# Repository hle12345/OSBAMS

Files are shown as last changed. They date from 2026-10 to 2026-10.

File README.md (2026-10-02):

# OSBAMS — Rev.2

> ## Status
> **Release candidate, not bench-validated.** The controller PCB (`Hardware/Rev2_Controller/OSBAMS_Rev2_RELEASE_CANDIDATE_1/`, RC1.2e) is a
> *review* package: ERC/DRC/netlist/schematic-parity checks are clean, but **no physical validation has been run**, the board is
> **not released for fabrication**, and nothing here is BENCH_TESTED or HARDWARE_VALIDATED. Gerbers are intentionally not shipped:
> export them yourself from the KiCad 10 project after re-running ERC/DRC. First-article tests and open items are listed in
> `Hardware/Rev2_Controller/CONTROLLER_PROTECTION_AND_CONNECTOR_AUDIT.md`. Do not connect a real battery pack to hardware built from
> these files without completing `docs/rev2/FIRST_BATTERY_TEST_PROCEDURE.md`.

> **AI assistance.** Developed with AI-assisted engineering tools (including Claude) for code generation, documentation, and design
> review. Final design decisions, hardware validation, and release responsibility remain with the project author/team.

## Licences
* **Software and firmware** (`desktop/`, `Firmware/`, `tools/`, `tests/`, build/calculation scripts): **MIT** — see `LICENSE`.
* **Hardware and hardware documentation** (`Hardware/`, `manufacturing/`, `docs/`, `Documentation/`, KiCad sources): **CERN-OHL-S-2.0** — see `LICENSE-HARDWARE.md`.
* Manufacturer datasheets and CAD models are **not** included; see `docs/rev2/pcb/evidence/SOURCES.md` for where to get them.

**OSBAMS Rev.2 is a standalone lithium-ion battery characterization platform optimized
around the SFSU Agilent 6060B electronic load. It uses an STM32L476RG safety controller,
Raspberry Pi 5 interface, INA228-based measurement, independent voltage verification, and
Keysight reference instrumentation to validate capacity, energy, DCIR, thermal behavior, and
battery health metrics of compatible lithium-ion battery packs within the verified hardware envelope.**

Supported: lithium-ion packs, approximately 30–42 V (10S-class; Ninebot/Segway, Shenzhen Elite), XT60 (connector type does not determine test capability — the validated power path does).
Status: **2.0.0-dev1 — host- and simulator-tested; no physical validation has been run**
(nothing is BENCH_TESTED or HARDWARE_VALIDATED).

## The one rule
`allowed current = min(battery profile, OSBAMS hardware limit, 6060B current limit, 300 W / battery voltage)`
at the conservative (never-sagging) pack voltage. 42 V → **7.14 A**; 36 V → **8.33 A**. The 60 A rating never
overrides 300 W. Operating ceiling: ≤ 44 V and ≤ 10 A until the power path is physically validated.

## The Rev.2 stack (`docs/rev2/SFSU_EQUIPMENT_MATRIX.md`)
Agilent/Keysight **6060B** (primary and only external load) · Keysight **EDU34450A** (reference measurement) ·
**Raspberry Pi 5 + 10.1" touchscreen** (UI, database, passport, reports) · **STM32L476RG** (safety controller) ·
**power path** (battery → XT60 → fuse → disconnect → relay → shunt → 6060B) · Keysight **EDUX1052G** (validation-only observation).

## Test orchestrator and dashboard
`services/test_orchestrator.py`: Capacity (`PROFILE → OCV screen → hardware safety check → capability calculation → READY → CC discharge → cutoff → load OFF verified → recovery → results`) and a separate DCIR current-step test. The dashboard shows the live permitted-current breakdown and drives a *manual* 6060B (operator sets/enables the load; OSBAMS verifies from measurements). Hard invariant: commanded current × conservative pack voltage ≤ 300 W; sag never raises current.

## Open at multiple levels
**Current status of the calibration / validation / AI work (under development)**
- The Rev.2 PCB remains frozen at RC1.2e (release candidate, not bench-validated until first article); the validation/AI work makes no PCB or schematic geometry change.
- Protocol v2 firmware is still under development: only a host-side reference parser, golden vectors and design exist; the STM32 firmware still speaks protocol v1.
- Calibration, measurement-quality and agreement thresholds (and the rule-baseline thresholds) are provisional until real bench/reference-instrument measurements exist.
- The AI/data work is experimental/research-stage; no ML-based battery-health result is production-valid yet, and capacity retention vs rated is not a validated cell-level SOH.

OSBAMS is a platform for assessing unknown and second-life batteries, not just a low-cost cycler: **open hardware** (Rev.2 controller PCB review package), **open firmware and software**, **open battery profiles and test protocols**, **open standardized data** (`docs/rev2/DATASET_SCHEMA.md`, Battery Passport) and **open health models** (`ai/`). Chain: Rev.2 hardware → calibration/validation layer → real battery dataset → explainable AI health assessment. The calibration/validation and AI work is **under development**: thresholds are provisional until reference-instrument validation, Rev.2 remains unbench-validated until first article, AI health estimation is experimental/research-stage, and capacity retention is not a validated cell-level SOH. See `docs/rev2/WORKSTREAMS.md`, `docs/rev2/VALIDATION_AND_CALIBRATION_PLAN.md`, `ai/README.md`.

## Next milestone: first real battery test
`docs/rev2/FIRST_BATTERY_TEST_PROCEDURE.md`, with `CALIBRATION_RECORD_TEMPLATE.md` and `HARDWARE_ACCEPTANCE_RECORD.md`. Software is ahead of hardware; no more features until measurements exist.

## Bench work
`docs/rev2/BENCH_CHECKLIST.md` — the exact physical tests, in order (workflow: `LV_HARDWARE_VALIDATION_PLAN.md`; verification: `INSTRUMENT_CALIBRATION_PLAN.md`). `docs/rev2/6060B_DRIVER_EVIDENCE.md` — remote-control command evidence (nothing VERIFIED yet).

## Controller PCB manufacturing package
`manufacturing/PCBWay_OSBAMS_Rev2_PCBA/` — candidate Gerber/BOM/CPL/PDFs for the KiCad controller PCB, with a design review and checklist. **Not production-ready** (see its README and checklist).

## Layout
- `desktop/` — Python application (`equipment/`, `services/`, `db/`, `gui/`)
- `Firmware/` — STM32 firmware + host C tests
- `docs/rev2/` — architecture, power-path matrix, current-sensing redesign, GPIB checklist, validation plan, baseline
- `legacy/rev1/` — archived Rev.1 code (nothing may import it)
- `tests/`, `tools/` — Python tests; simulator and demo-data tools

## Run the tests
```
pip install pytest numpy scikit-learn
python3 -m pytest tests          # also: pyserial PySide6 pyqtgraph; QT_QPA_PLATFORM=offscreen
make -C Firmware/Tests run
```
Learning Mode demo: `cd desktop && python3 -m services.learning_mode`.
Simulator: `python3 tools/simulate_serial.py --list`.

## 6060B remote control
`6060B_REMOTE_CONTROL = BLOCKED_BY_INTERFACE_CONFIRMATION` until the lab's GPIB
path is confirmed (`docs/rev2/GPIB_INTERFACE_CONFIRMATION.md`). Use `Manual6060B`
or `Simulator6060B` meanwhile.

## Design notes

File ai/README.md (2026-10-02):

# OSBAMS `ai/` — experimental health-assessment area

**Experimental / research stage.** Nothing here is a validated battery state-of-health or a safety certification. Thresholds are
provisional until reference-instrument validation and real labelled data exist. Capacity retention (measured usable ÷ rated) is not
a validated cell-level SOH.

Layout: `features/` (feature definitions, quick-test features) · `assessment/` (non-ML rule baseline: REUSE_CANDIDATE / MONITOR /
RETEST_REQUIRED / RECYCLE_CANDIDATE with reason codes; missing inputs or non-PASS quality can only give RETEST_REQUIRED) · `models/`
(small explainable zoo: linear/logistic, random forest, gradient boosting, Gaussian process — no deep networks) · `training/` (refuses to
train without enough validated, labelled batteries; synthetic data only with explicit opt-in) · `evaluation/` (split by battery identity,
metrics) · `datasets/` (clearly labelled SYNTHETIC generator and sample) · `model_registry/` (append-only record of dataset version, feature
version, model type, battery count, chemistry coverage, protocol, metrics, limitations).

The AI work uses the exported dataset (`docs/rev2/DATASET_SCHEMA.md`) or synthetic/test CSVs; it does not depend on protocol v2.
Quick Health Test: `docs/rev2/QUICK_HEALTH_TEST_RESEARCH.md`.

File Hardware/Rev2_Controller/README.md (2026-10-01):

# OSBAMS Rev.2 Controller (new integrated design)

Status: **RELEASE CANDIDATE 1.2 — design package for REVIEW. NOT final, NOT released for fabrication.**
- `OSBAMS_Rev2_RELEASE_CANDIDATE_1/` — KiCad 10 project (schematic, 4-layer PCB, TC74 probe board), BOM/CPL (no Gerbers: export them from the final PCB in KiCad 10), PDFs, ERC/DRC reports, evidence register, supply-chain/DFM/assembly/fab notes, `PCBWAY_RELEASE_CANDIDATE_REPORT.md` (READY FOR REVIEW / BLOCKERS BEFORE PCBWAY ORDER).
- `REV2_CONTROLLER_ARCHITECTURE.md` — architecture (rev D, matches RC1)
- `REV2_CALCULATIONS.md` — generated: `python3 Hardware/Rev2_Controller/calc/rev2_calcs.py` (inputs: `calc/datasheet_inputs.json`, evidence states VERIFIED_LOCAL / USER_RELAYED_MANUFACTURER / UNVERIFIED)
- `REV2_BLOCK_DIAGRAM.png/.svg` (`calc/make_block_diagram.py`), `DATASHEET_VERIFICATION.md` (evidence register)
- `design/` + `build_rc1.py` + `finalize_rc1.py` — generator pipeline (single source of truth `design/rev2_design.py`); `BUILD_ENVIRONMENT.md` explains the KiCad 10 container (`tools/kc10`).
- `reference/` — superseded drafts. Rev.1 KiCad: `legacy/reference/rev1_kicad/` (reference only).
Order: RC1 review → clear every blocker in the RC1 report (manufacturer PDFs, EB21A drawing, local ERC/DRC and Gerber regeneration, stock/lifecycle) → gates in `docs/rev2/pcb/RELEASE_GATES.json` → PCBWay.

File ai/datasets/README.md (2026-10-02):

# Datasets

`synthetic_sample.csv` and `synthetic.py` are **SYNTHETIC**: invented numbers from a made-up relation, for exercising the pipeline. They are
not measurements, not battery physics, and must never be cited as evidence. Real data come from `desktop/services/dataset_export.py`
(`docs/rev2/DATASET_SCHEMA.md`); contribute only anonymized exports.

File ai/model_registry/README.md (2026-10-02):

# Model registry
`registry.py` appends one JSON line per trained model (`registry.jsonl`, created on first use): model type, dataset and feature versions,
training battery count, chemistry coverage, test protocol, validation metrics, explanation, limitations, and a `synthetic` flag. A registry
entry is a record of what was done, not a claim that the model is validated.

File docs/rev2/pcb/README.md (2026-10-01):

# Controller PCB — status and documents
- `MANUFACTURING_STATE.md` — no package exists; gates in `RELEASE_GATES.json`
- `REV2_SCHEMATIC_PCB_PLAN.md` — proposed revision (board not modified)
- `BENCH_V1_V10_ONE_PAGE.pdf` / `.md` — hand-fill bench sheet (`python3 -m tools.mfg.bench_sheet`)
- `APPROVED_DECISIONS.md` — user decisions 2026-10-01
- `RELAY_VERIFICATION.md`, `PI_POWER_ARCHITECTURE.md`
- Audit inputs (unchanged): `PCBWAY_READINESS_GAPS.md`, `PCBWAY_REV2_CHANGE_REQUEST.md`, `REV1_HARDWARE_TRUTH_INVENTORY.md`
- `REV1_BOARD_*_SNAPSHOT.md` — historical

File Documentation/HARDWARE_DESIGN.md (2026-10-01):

# OSBAMS Hardware Design

> **Naming:** Rev.2 calls the sides "A. battery / discharge power path" and "B. low-voltage control / instrumentation path" (see `docs/rev2/HARDWARE_FREEZE_CANDIDATE.md`).
>
> **Rev.2 note:** the Rev.1 design below is retained for history. Rev.2 power-path limits and the redesign needed to use more of the 6060B envelope are in `docs/rev2/LV_POWER_PATH_CAPABILITY.md`; targets above 60 V are out of scope.

**Build:** 0.9.0-dev1 — Engineering Prototype
**Status:** The architecture is defined and captured in a block schematic. The
design is **not frozen**: the contactor, E-stop, sensor front end, and power
supply are still being selected, and no board has been built or bench-verified.
This document describes the intended design and marks what remains open.

Supporting files:
- `hardware/schematic/OSBAMS_schematic.svg` / `.png` — block schematic
- `hardware/bom/OSBAMS_BOM.csv` — bill of materials (27 line items)
- `hardware/wiring/CONNECTION_TABLE.md` — pin/net connection table
- `hardware/Calculations/` — fuse, shunt, divider, thermal calculations (pending)

---

## 1. Design intent

OSBAMS is a bench fixture for discharging and measuring second-life 10S NMC
packs (36 V nominal, 42 V maximum, up to ~10 A). It is an engineering
instrument, not an EV drivetrain, so switching and protection are sized to the
actual energy of the pack under test — not to hundreds of amps.

Two guiding principles:

1. **Physical safety does not depend on firmware.** An E-stop must remove
   contactor-coil power by hardware, even if the firmware hangs, USB is removed,
   or the desktop freezes.
2. **The controller survives a pack disconnect.** Control power is separate from
   the pack, so the STM32 can save state, log the fault, and send the last
   telemetry when the pack is removed.

---

## 2. High-energy power path

```
Battery +  →  keyed connector (J1)  →  58 V DC fuse (F1)
           →  Blue Sea manual disconnect (SW1)
           →  DC contactor (K1)
           →  precision shunt (RS1) / INA228
           →  electronic load
           →  Battery −  (single-point star ground)
```

Notes and open items:
- **Connector (J1):** keyed/polarised (XT60 or Anderson) so the pack cannot be
  connected backwards casually.
- **Fuse (F1):** DC-rated with a **documented DC interrupt rating** at this
  voltage — not a generic automotive fuse. Value from `hardware/Calculations/`
  (pending).
- **Manual disconnect (SW1):** Blue Sea 6006, a physical service disconnect that
  breaks the pack rail.
- **Contactor (K1):** a **DC-rated** contactor with a published DC breaking
  rating for 42–60 V under load. The specific part is **not yet frozen** — this
  is the single most important remaining hardware selection, and it must not be
  a generic relay whose datasheet lacks a DC interrupt rating.
- **Shunt (RS1):** external shunt sized so full-scale current stays within the
  INA228's ±163.84 mV shunt range. Kelvin connection. Value pending calibration.

---

## 3. Control path (separate 12 V)

```
120 VAC  →  12 V supply (PS1)
         ├─────────────────────────────┐
         │                             │
  contactor-coil branch          5 V branch
   F2 control fuse                12→5 V converter
   ARM switch (SW2)               →  STM32
   E-stop NC (ES1)
   MOSFET low-side driver (Q1)  →  contactor coil (K1)
```

The E-stop is wired in series with the contactor coil supply as a
**normally-closed** contact, so opening it de-energises the coil directly,
independent of the STM32. The MOSFET (Q1) is only the low-side switch the STM32
uses to command the coil **within** that safety chain — it cannot override an
open E-stop. A flyback/suppression diode across the coil is required (see BOM).

Open items: the E-stop part, the 12 V supply, and the MOSFET are selected in the
BOM as starting points but not frozen.

---

## 4. Measurement and sensing

| Quantity | Device | Notes |
|---|---|---|
| Bus voltage, current, power, energy, charge | INA228 (U2) | primary metrology; 85 V bus covers 42 V pack; external shunt |
| Redundant voltage | STM32 ADC via protected divider | diverse cross-check, gross-error only, **not** certified-independent |
| Pack temperature | TC74 (U3) | I²C, 1 °C resolution |

The INA228 and TC74 share the I²C bus (PB8/PB9) with pull-ups. The ADC divider
scales the 42 V pack into the 3.3 V ADC range; its exact ratio, resistor
tolerances and voltage ratings, RC filter, input protection, and ADC sample time
are part of the analog design still to be finalised in `hardware/Calculations/`.

---

## 5. STM32 connections

| Signal | Pin | Direction | To |
|---|---|---|---|
| I²C SCL / SDA | PB8 / PB9 | bidir | INA228, TC74 |
| Load enable | PC8 | out | Q1 gate (contactor coil driver) |
| Contactor aux feedback | PC9 | in | K1 auxiliary contact |
| E-stop sense | PA0 | in | E-stop / disconnect status |
| UART TX / RX | PA2 / PA3 | bidir | USB virtual COM (host) |
| Heartbeat LED | PA5 | out | status LED |
| Redundant voltage | ADC channel | in | protected divider |

Full net-by-net detail is in `hardware/wiring/CONNECTION_TABLE.md`.

---

## 6. Protection (engineering review pending)

The following must be reviewed and specified before the design is frozen. They
are listed here so the gap is explicit, per the design review:

- DC fuse interrupt rating at the working voltage
- TVS / transient suppression on the pack input
- Reverse-polarity handling (keyed connector in V1; firmware polarity check)
- Contactor-coil flyback / bidirectional suppression
- Shunt Kelvin connections
- USB ESD protection
- Grounding and ground-loop control (single-point star)
- Connector touch safety, covered terminals, cable strain relief
- Enclosure with separation of high-energy wiring from logic

---

## 7. Bill of materials

See `hardware/bom/OSBAMS_BOM.csv`. Each line item carries manufacturer, part
number, rating, quantity, supplier, and Installed/Verified status. The
biggest-ticket item is the contactor. Every "Verified" field is currently No,
because nothing has been built. Before the design is frozen, the BOM must have a
DC-rated contactor and fuse with documented interrupt ratings, a finalised shunt
value, and an approved substitute for each critical part.

---

## 8. What "frozen" will require

The hardware moves from Engineering Prototype to a frozen revision only when:

- the schematic is complete (not a block diagram) and reviewed,
- the BOM has exact, in-stock parts with documented DC ratings,
- the protection review in §6 is closed,
- the board (PCB or well-organised perfboard) is built and matches the schematic,
- and the acceptance tests in `VALIDATION_REPORT.md` that touch hardware pass
  with recorded data.

Until then this remains a documented design, not verified hardware.

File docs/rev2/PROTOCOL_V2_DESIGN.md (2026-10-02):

# Serial protocol v2 — design (firmware NOT changed)

**Status: design plus a host reference implementation (`desktop/services/protocol_v2.py`). The STM32 firmware still speaks protocol v1.
Nothing here has run on hardware.** v1 (`services/protocol.py`, CRC-16/CCITT-FALSE) stays authoritative for the existing firmware and is
still accepted by `parse_any`.

## Why
The three-way capacity cross-check (`VALIDATION_AND_CALIBRATION_PLAN.md` §4) needs three things v1 does not carry: the independent STM32
ADC voltage, the INA228's own charge/energy accumulators, and the STM32's own timestamp-based integration, plus counters and a
sensor-status word so the Pi can tell "unavailable" from "zero" and "lost frame" from "lost acquisition".

## Frame
`OSBAMS,2,<seq>,<tick_ms>,<V_mV>,<I_mA>,<P_mW>,<T_C10>,<flags>,<state>,<V_adc_mV>,<Q_ina_uAh>,<Q_mcu_uAh>,<E_ina_uWh>,<E_mcu_uWh>,<acq_count>,<sensor_status>,<CRC16>`
(18 fields). Fields 0–9 mean exactly what they mean in v1. Fields 10–14 are integers or the literal `NA`; `NA` is never replaced by 0.
Field table, accumulator rules and `sensor_status` bits: module docstring of `protocol_v2.py` (SS_INA_FAULT, SS_ADC_FAULT, SS_TEMP_FAULT,
SS_ACCUM_INVALID, SS_TIME_JUMP).

## Rules
1. v1 backward compatibility: a v2 reader accepts v1 frames (new fields unavailable); a v1 reader never sees a v2 frame unless the
   firmware is upgraded.
2. All four accumulators reset together at an explicit test-start command. A decrease between frames, or `SS_ACCUM_INVALID`, makes the
   Pi flag `CAPACITY_VALIDATION_WARNING`; it never silently re-baselines.
3. INA228 accumulators are valid only when ADCRANGE/SHUNT_CAL match the active calibration profile (firmware sets `SS_ACCUM_INVALID` otherwise).
4. Like-for-like: the device integrates its own uncalibrated readings, so the agreement check uses the RAW Pi samples; the calibrated Pi
   result is reported separately and is the one used for capacity retention.
5. Nothing in the protocol can change relay, E-stop or load-control behaviour.

## Test-first firmware plan
Golden frames: `docs/rev2/protocol_v2_test_vectors.json` (valid, NA fields, v1 still accepted, bad CRC, wrong field count). Host tests:
`tests/test_protocol_v2_and_data.py`. Firmware order of work: (1) add C tests in `Firmware/Tests` that encode/parse these vectors; (2)
implement the encoder; (3) expose the INA228 CHARGE/ENERGY registers; (4) add STM32 timestamp integration; (5) bench-compare on the
first-article rig. The Pi side and the AI/data work do not wait for any of this.

## Pi-side comparison at test completion
`services/capacity_validation.py`: `AccumulatorTracker` consumes samples, `validate()` returns Ah and Wh per method, % disagreement,
sample and missing-sample counts, calibration id, firmware version, PCB revision, and status `OK` / `CAPACITY_VALIDATION_WARNING` /
`INSUFFICIENT` (fewer than two totals available — never reported as agreement). The warning threshold is **PROVISIONAL** (default 1 %,
configurable) until bench data set it. Persisted by `run_persistence.save_capacity_validation`.

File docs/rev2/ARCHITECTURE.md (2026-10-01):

# OSBAMS Rev.2 architecture

## Identity
> OSBAMS Rev.2 is a standalone lithium-ion battery characterization platform
> optimized around the SFSU Agilent 6060B electronic load. It uses an
> STM32L476RG safety controller, Raspberry Pi 5 interface, INA228-based
> measurement, independent voltage verification, and Keysight reference
> instrumentation to validate capacity, energy, DCIR, thermal behavior, and
> battery health metrics of compatible lithium-ion battery packs within the
> verified hardware envelope.

Supported batteries: lithium-ion (NMC/NCA/LFP), approximately 30–42 V, 10S-class
(Ninebot/Segway, Shenzhen Elite). Connector: XT60 = supported; connector type does not determine test capability — the validated power path does.
Removed scope is recorded only in `docs/research/OUT_OF_SCOPE_FOR_REV2.md`.

## The Rev.2 equipment stack
1. **Agilent/Keysight 6060B** — the only external load; primary test load (CC/CV/CR; capacity, energy, DCIR steps).
2. **Keysight EDU34450A** — reference measurement for calibration/verification; not in the automated loop.
3. **Raspberry Pi 5 + 10.1" touchscreen** — UI: test control, live dashboard, SQLite database, battery passport, reports, analysis.
4. **STM32L476RG** — real-time safety controller: acquisition, relay control, fault handling, watchdog, E-stop monitoring.
5. **Power path** — battery → XT60 → fuse → disconnect → relay → current shunt → 6060B.
6. **Keysight EDUX1052G** — validation only: relay switching, shutdown timing, transients, load-enable behavior.

*The Pi requests actions. The STM32 authorizes them.* (Design principle; today the orchestrator supervises a manual 6060B and verifies load-off from measurements — it does not command the STM32.)

## Envelope
`allowed current = min(battery profile, OSBAMS hardware limit, 6060B current limit, 300 W / battery voltage)`
using the **conservative pack voltage** (max of OCV and highest seen, never lowered by sag) and including the
fuse, disconnect, relay, shunt, wiring and connector limits inside "OSBAMS hardware". 42 V → 7.14 A; 36 V → 8.33 A.
The 60 A rating never overrides 300 W. Operating ceiling: **≤ 44 V, ≤ 10 A (provisional)** until the power path is
physically validated. The firmware hard trip (18.5 A / 60 °C) is a separate protection boundary, not an input to the minimum.

## Test pipeline
```
battery profile → OCV screen → hardware safety check → 6060B capability calculation
→ controlled load test → live logging → Ah/Wh integration → DCIR step
→ automatic cutoff → recovery → SOH / report / passport
```
`services/test_orchestrator.py`: `CapacityTest` (OCV, constant-current discharge, Ah, Wh, voltage sag, thermal
monitoring, automatic profile cutoff, verified load-off, recovery) and a separate `DcirTest` (current steps). The
hardware safety check logs each check (registry status, temperature present and in limits, voltage envelope, positive
permitted current, ceiling below firmware trip, load idle) and blocks before any load command. FAULT paths always turn the
load off and verify it from measured current. Results: `services/run_persistence.py`; history, grading, report and
passport use the existing registry/DB/PDF modules. The dashboard shows pack voltage, profile limit, OSBAMS limit, 6060B
rating, power-derived limit, FINAL PERMITTED and the limiting factor.

## Code map (`desktop/equipment/`)
`capability.py` (envelope + invariant) · `inventory.py` (stack) · `drivers/` (`Keysight6060B` — blocked; `Manual6060B` — working mode; `Simulator6060B`) ·
`reference/` (EDU34450A calibration records) · `validation.py` (ordered bench workflow → `BENCH_CHECKLIST.md`).
Driver evidence: `6060B_DRIVER_EVIDENCE.md`.

## Smart BMS
Supported, documented low-voltage lithium-ion packs, normal read-only communication only. Nothing is implemented or verified,
so every pack reports `SMART_PACK_UNSUPPORTED`. No BMS bypass.

## Known gaps (honest status)
- 6060B remote control: no confirmed GPIB path and no command VERIFIED (the official manuals were not readable from the build environment).
- Orchestrator/dashboard are host- and simulator-tested only; the Pi 5 deployment is untested; **no physical validation has been run** — nothing is BENCH_TESTED or HARDWARE_VALIDATED.
- Power-path parts not yet read off the hardware; the 15 A fuse sits below the 18.5 A firmware trip (decision open).
- TC74 not brought up: thermal protection unvalidated; the safety check refuses to start without a temperature reading.
- No variable source is part of the stack, so voltage/current are verified at the pack's own operating points (`INSTRUMENT_CALIBRATION_PLAN.md`).

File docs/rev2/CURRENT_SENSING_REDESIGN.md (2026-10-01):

# Current sensing — no redesign planned

**Decision:** the Rev.1 current path (RSA-20-50, 2.5 mΩ, ~20 A class, INA228) is
**kept unchanged**, and the OSBAMS operating ceiling stays at **10 A,
provisionally** (`config.SAFETY_MAX_CURRENT_A`).

Why: every supported pack is 36–42 V (≤ 44 V ceiling). The 6060B's 300 W limit
allows 300 / 42 = **7.14 A** (8.33 A at 36 V), and the profiles are lower still.
The existing path already exceeds any current these packs can be loaded with.

Layered limits (distinct concepts, deliberately not equal):

| Layer | Value | Meaning |
|---|---|---|
| Firmware hard safety trip | 18.5 A | absolute protection boundary |
| OSBAMS operating ceiling | 10 A | operating/test boundary (provisional) |
| 6060B @ 42 V | 7.14 A | `min(60 A, 300 W / V)` |
| Battery profile | e.g. 1–5 A | per pack |
| **Commanded maximum** | **min of the operating layers** | e.g. 5 A for a profile limit of 5 A |

The only thing to measure is whether the existing shunt/INA228 is accurate enough at
the 1–3 A test currents — that is bench step E1, not a redesign.

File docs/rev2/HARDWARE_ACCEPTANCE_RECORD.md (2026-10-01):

# Hardware acceptance record — OSBAMS Rev.2 power path and controls

Complete before the first battery connection (`FIRST_BATTERY_TEST_PROCEDURE.md` §1). Read every part number **off the
installed part**; the "expected" column is what the repository says, not proof. Anything not read stays UNKNOWN.
This record does not make the hardware BENCH_TESTED or HARDWARE_VALIDATED; it records what is installed.

## 1. Identification
| Field | Value |
|---|---|
| Unit / enclosure | |
| Date / operator | |
| Software commit / firmware version | |
| Photos stored at | |

## 2. Power path — as installed
| Ref | Part | Expected (source) | **As-installed part number** | Rating read from datasheet | Datasheet ≥ requirement? | Verified (Y/N) |
|---|---|---|---|---|---|---|
| J1 | Battery connector | Amass XT60 (BOM, purchase list: genuine XT60; datasheet figures: ~500 V DC, 60 A on 8 AWG, lower on thinner wire) | | | needs ≥ 10 A at the 12 AWG wire in use | |
| F1 | Main DC fuse | **15 A**, ≥ 58 V DC, Littelfuse/Eaton DC fuse (purchase list: "HOLD - verify part") | | | DC interrupt rating documented? | |
| FH1 | Fuse holder | Littelfuse 0FHM0001ZXJ-RED holder (per purchase record; verify DC V/A rating — V5) with fuse Littelfuse 0997015.WXN 15 A / 58 V | | | accepts the chosen fuse style? | |
| SW1 | Manual disconnect | Blue Sea 6006 (48 V DC max, 300 A continuous, 25 A switching — distributor listings) | | | ≥ 44 V system ceiling | |
| K1 | Relay / contactor | firmware records **Durakool DG57CM-5021-76-1012-R** (no aux contact). BOM/purchase spreadsheets still say Albright SW60 — stale | | | DC rating at ≥ 44 V / 10 A from the datasheet for THIS suffix; coil voltage 12 V? | |
| RS1 | Current shunt | firmware: **RSA-20-50** (2.5 mΩ, 20 A / 50 mV); purchase list: "15 A or 20 A / 50 mV candidate" | | | rating, tolerance, power | |
| W1 | Power wiring | 12 AWG, ≥ 60 V insulation | | | ampacity for the cable actually fitted | |
| — | Ring terminals / lugs | matched to studs | | | | |

Layered limits to confirm against the above: battery profile · 6060B 300 W/V · **OSBAMS operating limit 10 A** ·
**fuse 15 A (abnormal fault current only)** · firmware trip 18.5 A · shunt 20 A. Enter any rating that is *below* 10 A here: ____

## 3. Control and measurement hardware — as installed
| Ref | Part | Expected | As-installed | Notes |
|---|---|---|---|---|
| U1 | STM32L476RG Nucleo-64 | NUCLEO-L476RG | | |
| U2 | INA228 | Adafruit 5832 breakout | | shunt cal matches RS1? |
| U3 | TC74 | TC74A0-5.0VAT (address 0x48) | | **thermal protection unvalidated until working**; attachment point on the pack: |
| Q1 / D1 | coil driver / flyback | IRLZ44NPBF / 1N5408G (per purchase record; confirm installed — V8) | | |
| ES1 | E-stop (NC) | Eaton M22-PV-K02 (per purchase record; verify NC contact count — V6) | | wired in series with the coil supply |
| SW2 | ARM switch | C&K T102SHZQE SPDT (per purchase record; verify — V6) | | |
| PS1 | 12 V supply | Mean Well XDR-75-12 (12 V / 6.24 A / 74.88 W) | | purchase list only says "≥ 2 A, TBD" |
| DCDC1 | 12→5 V | undefined — decision pending, see `pcb/PI_POWER_ARCHITECTURE.md` (external 5 V recommended) | | **a Pi 5 needs a much larger 5 V budget — specify before powering the Pi from it** |
| VO610A feedback | K1 voltage feedback on PC9 | firmware: PC9 = VO610A, active low | | confirm wiring matches |
| ADC divider | independent voltage channel | **unfinished** (purchase list: "DO NOT ORDER YET") | | needed for bench step C2 |
| TVS | pack-input protection | **unfinished** (purchase list: hold) | | |

## 4. Visual and wiring checks (power off, pack not connected)
- [ ] Matches `HARDWARE_FREEZE_CANDIDATE.md` power path; shunt in series; sense leads on the Kelvin terminals
- [ ] High-energy wiring separated from logic; studs covered; strain relief; labels (polarity, fuse rating)
- [ ] Enclosure grounding present

## 5. Continuity / polarity (EDU34450A, power off)
| Check | Reading | OK? |
|---|---|---|
| + to − (must be open) | | |
| Relay contacts, coil de-energised (must be open) | | |
| Fuse continuity | | |
| Shunt resistance | ____ mΩ (expect ≈ 2.5 mΩ if RSA-20-50) | |
| Polarity marks match meter test of the connector | | |

## 6. Safety-function checks (no battery) — bench steps B2, B3
| Function | Expected | Result | Evidence file |
|---|---|---|---|
| Relay default state | open after reset/brown-out/unprogrammed MCU | | |
| E-stop de-energises the coil with the firmware dead (MCU held in reset) | coil off | | |
| ARM off → no relay command | | | |
| Sensor unplugged → FAULT, load-enable OFF | | | |
| Host disconnect → FAULT/safe state | | | |
| Relay close / open times (EDUX1052G, ≥ 10 repetitions) | recorded | | |

## 7. 6060B interface (remote control stays blocked until confirmed)
| Question | Answer |
|---|---|
| Rear-panel interface present (GPIB connector, any other)? | |
| GPIB address setting | |
| USB↔GPIB adapter / LAN↔GPIB gateway / GPIB-equipped PC available at SFSU? | |
| Result | `6060B_REMOTE_CONTROL = BLOCKED_BY_INTERFACE_CONFIRMATION` until a concrete interface is identified **and** commands are VERIFIED (`6060B_DRIVER_EVIDENCE.md`). The first battery test uses the manual front panel. |

## 8. Decision
☐ **ACCEPTED for the first relay-open / low-current test** — all rows in §2 and §3 for the power path and E-stop read and recorded, no rating below 10 A, §6 checks pass.
☐ **NOT ACCEPTED** — reasons: ____

Operator / date: ____________   Reviewer / date: ____________

Statuses BENCH_TESTED and HARDWARE_VALIDATED are not set here. They may be claimed only for what the executed
bench steps (`BENCH_CHECKLIST.md`) actually measured, with data stored.

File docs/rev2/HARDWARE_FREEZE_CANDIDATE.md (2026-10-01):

# Rev.2 hardware — freeze candidate

Status: **candidate, not frozen.** Exact installed part numbers are still to be read off the
hardware (§6; record them in `HARDWARE_ACCEPTANCE_RECORD.md`). Nothing here is bench-validated.

Naming: the two sides are **A. Battery / discharge power path** and
**B. Low-voltage control / instrumentation path** — not "HV/LV". The battery
side is only ~30–44 V for the packs on hand.

## 1. Envelope (layered; three different things)
| Layer | Value | Notes |
|---|---|---|
| 6060B instrument rating | 3–60 V, 60 A, 300 W | `I_max = min(60 A, 300 W / V)`; not an OSBAMS claim |
| **OSBAMS system ceiling (provisional)** | **44 V**, **10 A** | `config.OSBAMS_VALIDATED_MAX_VOLTAGE_V`, `SAFETY_MAX_CURRENT_A`; the finished system is **not** a "60 V system" |
| Firmware hard trip | 18.5 A, 60 °C | protection boundary, not an operating limit |
| Pack at 42 / 36 / 30 V (6060B) | 7.14 / 8.33 / 10 A | power-limited first |

## 2. A. Battery / discharge power path
```
USED Li-ion PACK (10S-class, ~30-42 V) → XT60 connector (adapter only if needed)
  → FUSE (15 A target) → BLUE SEA 6006 manual disconnect
  → DURAKOOL DG57CM relay (SPST-NO, 12 V coil; firmware records DG57CM-5021-76-1012-R)
  → CURRENT SHUNT (existing 20 A class, Kelvin sense, IN SERIES with the current)
  → AGILENT 6060B (3-60 V / 60 A / 300 W) → battery −
```
| Part | Rating used | Verification level |
|---|---|---|
| Blue Sea 6006 | 48 V DC max, 300 A continuous, **25 A switching** | manufacturer-spec values as shown in distributor listings; not read from a Blue Sea datasheet here |
| Durakool DG57CM | DC switching ~80 A@12 V, 60 A@36 V, 50 A@48 V, 145 V DC max, 6–50 V coils — **depends on the exact variant** | from the Durakool product listing; exact suffix of the physical relay NOT yet read |
| Fuse | 15 A target | part/holder not confirmed; needs a DC voltage rating ≥ 44 V (≥ 48 V preferred) |
| Shunt | 20 A class (RSA-20-50, 2.5 mΩ per repo) | exact installed part not yet confirmed |
| INA228 | bus 85 V | covers 44 V with wide margin |
| XT60 (Amass) | ~500 V DC; 60 A on 8 AWG, lower on thinner wire (spec-sheet summaries) | XT60 = supported. **Connector type does not determine test capability — the validated power path does.** |

Current-sensing redesign stays deferred (`CURRENT_SENSING_REDESIGN.md`).
Not to be bought/added: EV200, precharge, SB120, 90 A wiring — none increases what a 300 W load can test on these packs. **Relay note:** the BOM/purchase spreadsheets still list an Albright SW60; the firmware (`load_driver.c`) records the Durakool DG57CM-5021-76-1012-R as K1. The spreadsheets are stale — confirm the physical relay and update them.

## 3. B. Measurement, temperature, safety, power, UI
- **Measurement:** INA228 (primary V/I/P) and an independent ADC divider cross-check feed the STM32L476RG. Calibrate both against the EDU34450A.
- **Temperature:** TC74 (I²C, 1 °C) on the pack surface for the first build. **Thermal protection is not validated** until the TC74 works and is attached at a sensible location; later add shunt / relay / connector sensors.
- **Safety path (independent of the Pi):** 12 V → E-stop (NC) in series with ARM → relay-coil permission → DG57CM coil. In parallel, E-stop status, ARM status, relay command (MOSFET driver) and relay feedback go to the STM32. The Pi must never be the last thing between a fault and the relay opening.
- **Auxiliary power:** 120 VAC → Mean Well XDR-75-12 (12 V / 6.3 A, adjustable 12–15 V) → relay coil, controls, and 5 V rails. Pi 5 is specified for 5 V / 5 A and the Waveshare 10.1" panel ~5 V / 0.8 A, so size the converter **≥ 7 A** regulated, or better two rails: 5 V / 5 A for the Pi and 5 V / 1–2 A for display/control, keeping Pi transients off the measurement rail.
- **UI path:** STM32 → USB/UART → Raspberry Pi 5 (SQLite, OSBAMS application) → HDMI/USB touch → 10.1" screen. STM32 owns deterministic safety; Pi owns application/storage/UI. (The current software is the PySide6 desktop app; the Pi 5 deployment has not been tested.)
- **External instruments (outside the enclosure):** 6060B (the only one in the normal test power path); EDU34450A (reference measurement); EDUX1052G (validation-only observation).

## 4. Enforced in software now
44 V system ceiling and 10 A ceiling in `equipment/capability.py` (packs above 44 V are refused even though the 6060B accepts 60 V); the 15 A fuse, 20 A shunt and 48 V disconnect rating are in `REV2_POWER_PATH`; firmware `OSBAMS_DEFAULT_MAX_VOLTAGE_MV` (44000) is checked equal to the config ceiling by `tests/test_protocol.py`. Simulator scenarios are all 36–44 V lithium-ion.

## 5. Layered current limits (documented, not a defect)
| Layer | Value | Purpose |
|---|---|---|
| Battery profile | e.g. 1–7 A | per-pack test current |
| 6060B at the pack voltage | 300 W / V (7.14 A at 42 V) | instrument power limit |
| **OSBAMS operating limit** | **10 A** | normal operating/test boundary, enforced in software |
| **Fuse** | **15 A** | protects wiring/hardware against **abnormal fault current**, not normal regulation |
| Firmware hard trip | 18.5 A | absolute electronic protection boundary |
| Shunt rating | 20 A | measurement range |

A 15 A fuse with a 10 A software limit is a reasonable arrangement: the software controls
normal operation and the fuse is the passive last resort. Between 15 A and 18.5 A the fuse, not the
firmware, is what acts; that is accepted and documented rather than forced to match.

## 5b. Other items to keep in view
1. **Shunt placement** must be in series with the load current; high-side vs low-side must follow the existing INA228 PCB and grounding (not yet checked against the KiCad files).
2. **Blue Sea 6006 switching rating (25 A)** is fine at ≤ 10 A, but the relay does the switching; do not open the disconnect under load as routine.
3. **Relay ratings are variant-specific**; the relay current rating stays "unspecified" in the capability model until the datasheet for the installed part is read.
4. **Independent ADC divider and TVS are unfinished** (purchase list: "DO NOT ORDER YET"). Bench step C2 needs the divider built.
5. **12→5 V sizing**: the purchase list specifies ≥ 2 A for the DC/DC converter; a Pi 5 needs a much larger 5 V budget (see §3).

## 6. Needed before freezing (read off the installed hardware)
1. Relay part number (firmware: DG57CM-5021-76-1012-R) and its datasheet rating. 2. Shunt part number/spec (firmware: RSA-20-50). 3. The exact 12→5 V DC/DC converter(s) and the Pi 5 5 V supply. 4. Exact fuse and fuse-holder part numbers (DC rating). 5. XT60 supplier (genuine Amass). 6. The 6060B interface method. All go in `HARDWARE_ACCEPTANCE_RECORD.md`.

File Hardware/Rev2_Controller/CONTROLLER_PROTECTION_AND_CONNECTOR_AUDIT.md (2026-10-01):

# OSBAMS Rev.2 controller — protection and connector audit (RC1.2e)

**Status: RC1.2e review candidate — NOT RELEASED FOR FABRICATION. READY FOR THE OWNER'S LOCAL KICAD 10 EXPORT (see the blockers section).** Baseline audited: RC1.2d (ERC 0, DRC 0, unconnected 0). Result of this audit: **two board changes** (J9 land pattern, D15 differential clamp); the INA228 limits are now **read from the TI datasheet** (±40 V differential is a true absolute maximum); the ERJP08 voltage ratings are read locally (500 V limiting / 1000 V overload; the relayed 125 V / 500 V does not match the catalog row) and the SMF12CA values are read from the Littelfuse datasheet; the ERJP08 sheet AOA0000C331 has been read (it publishes **no pulse curve**; X2 closed by decision RC-A = YES) and the Molex 3D models were read (J5/J6 mechanical geometry matches; X1 closed with a pad/drill residual covered by F7). Evidence tags: none = VERIFIED_LOCAL (read by the build), **[UR]** = USER_RELAYED_MANUFACTURER, **[UV]** = UNVERIFIED (assumption/estimate). Surge and ESD are treated as separate problems.

**Definition used for the audit** (bench lithium-ion characterization, not an automotive or mains product): PACK_INA/INA228 VBUS normal 30–42 V, ceiling 44 V, INA228 absolute maximum / common mode 85 V (TI datasheet); Kelvin pair on the RSA-20-50 (2.5 mΩ): 10 A → 25 mV, 18.5 A (firmware trip) → 46.25 mV, 20 A → 50 mV, INA228 IN+ to IN− differential absolute maximum ±40 V (TI datasheet §6.1); PACK_ADC divider 75 k + 75 k / 10 k (16:1): 30 V → 1.875 V, 36 V → 2.250 V, 42 V → 2.625 V, 44 V → 2.750 V, then 1 k to PA1 (cross-check channel only). Credible events: hot-plug and contact bounce, load/relay interruption ≤ 18.5 A, ESD at accessible connectors, one Kelvin lead early/open, reversed wiring where reasonably protectable. Not in scope: automotive load dump, lightning, mains surge.

**Protection classification (RC1.2e):** (1) *modeled normal-transient protection* (hot-plug, bounce, load/relay interruption ≤ 18.5 A, one-Kelvin-lead cases) = **PASS** against datasheet-verified limits (INA228 85 V / ±40 V from the TI datasheet; 1.5SMBJ48A from Bourns; SMF12CA from Littelfuse; ERJP08 500 V / 1000 V from Panasonic, all read locally), with modeled values labelled as model results; (2) *ESD at the connectors* = `ESD_FIRST_ARTICLE_CONDITIONAL` — protection is **not demonstrated** (Panasonic publishes no ERJP08 pulse curve; ≈ 1.3 kV across R41 at 8 kV exceeds its 1000 V overload rating) and is accepted as a first-article test (F1, F5) only under release condition RC-A = YES (J5/J6 internal, permanently mated, not user-accessible); the RC1.3 connector-side clamp is the **documented fallback** if F1/F5 fail or bare pins are ever exposed; (3) **no remaining fabrication blocker**. Reversed pack at J6 is a **documented prohibited connection** (J6 is a polarized KK header; the harness must not be reversible); no board area is spent on −44 V miswiring.

## PASS

1. **J9 land pattern now matches the Samtec drawing** (details in appendix D). Samtec recommended PCB layout rev H: pads 0.74 × 2.79 mm, 1.27 mm pitch, 6.86 mm pad span, -K has no locating hole. RC1.2d used the generic KiCad pads 0.74 × 2.40 mm on a 6.30 mm span (0.39 mm too short, 0.56 mm too narrow a span). RC1.2e uses a custom footprint `OSBAMS_Rev2:FTSH-105-01-L-DV-K` built from the drawing; pin 1 / pin 2 / pin 3 positions were mapped to the drawing view by a 90° rotation (same handedness, no mirror).
2. **Hot-plug onto a live 44 V pack (appendix B1):** worst case over 3 harness inductances × 3 TVS capacitances — see the table: the 85 V limit holds with large margin because 44 V stays below the TVS knee (VBR min 53.3 V); the resistors limit ringing.
3. **Interruption of ≤ 18.5 A (appendix B3):** INA228 node ≤ 76.5 V even in the gross over-estimate where the whole interrupted current is forced into the sense TVS with no series resistor (limit 85 V); resistor energy ≈ ½·L·I² = 0.34 mJ for 2 µH (integrator ≤ 0.37 mJ).
4. **Normal-operation error of the new resistors** (appendix B7) stays inside the 0.1 % cross-check budget: R41 57 Ω into the VBUS input gives ≤ 0.007 % gain error (removed by calibration); Kelvin R42/R43/R11/R12 are matched and carry only bias/leakage.
5. **PA1 stays in range for every event that reaches the ADC divider** (appendix C): normal 1.875–2.750 V; clamped maximum ≈ 3.35 V; reversed pack ≈ −0.3 V with 0.27 mA injection.
6. **One-Kelvin-lead-open / late-connect is bounded** (appendix B5): with the INA228 powered and C26 intact, the 100 nF across the pins keeps the difference of a fast step at ≈ 1 % (≈ 0.4 V for 44 V) and the INA228's own differential input path holds it at ≪ 1 V afterwards; with D15 fitted the difference is also bounded to its clamp level (≤ about 15–20 V, limit 40 V) when the INA228 is unpowered / power-cycling or C26 has failed open — the cases where nothing else holds the open pin.
7. **Board checks after the RC1.2e changes:** ERC 0, DRC 0 (electrical and silkscreen), unconnected 0, netlist vs PCB 0 mismatches over 405 pads, diode polarity none wrong, host/controller isolation ≥ 1.0 mm on every layer (0.998 mm measured = polygon rounding, KiCad DRC enforces the exact rule), isolation-rule activity check passes. (Numbers in `NETLIST_CHECK.txt`, `ISOLATION_CHECK.txt`, `ISOLATION_RULE_CHECK.txt`, `DRC_REPORT.rpt`, `ERC_REPORT.rpt`.)

## CHANGE REQUIRED

**Made in RC1.2e**

| # | Change | Why | Effect on the board |
|---|---|---|---|
| C1 | J9 generic KiCad footprint → `OSBAMS_Rev2:FTSH-105-01-L-DV-K` (pads 0.74 × 2.79, rows 4.07 mm apart) | Samtec recommended layout rev H differs from the generic footprint (pad length 2.40 → 2.79 mm, pad span 6.30 → 6.86 mm) | J9 breakout re-routed: SWCLK and NRST moved into the 1.28 mm gap between the pad rows (x = 160.35), NRST via moved west to (155.8, 140.08); nothing else on the board moved (`design/rc12e_patch.py`) |
| C2 | **D15** (SMF12CA, bidirectional TVS, Diode_SMD:D_SMF) across INA_INP / INA_INN, placed at (119.25, 120.75) with 4 vias on the INA_INP/INA_INN copper | INA228 IN+ to IN− differential absolute maximum is ±40 V (TI §6.1); D5/D6 are ground-referenced 48 V TVS and cannot limit a difference. With the INA228 unpowered (or power-cycling) and one Kelvin lead open, nothing holds the open pin and it can drift 44 V away from the connected one; C26 failing open, or a one-sided ≈ 80 V ESD/clamp pulse that C26 does not fully absorb, create the same stress. D15 is a cheap backstop for these cases | +1 part (SMF12CA, SOD-123FL; pads identical to KiCad D_SMF), 2 pads, 4 vias, ≈ 8 mm of routing on F.Cu / B.Cu / In2.Cu; the rest of the routing is unchanged (`design/rc12e_merge.py` takes only the INA_INP/INA_INN copper from an incremental autoroute) |
| C3 | Evidence register: `rs_pulse_rating` reverted to **UNVERIFIED / critical** (catalog DC and ESD ratings are kept as the separate VERIFIED_LOCAL entry `rs_catalog_ratings`); `ina228_diff_max`, `ina228_cm`, pin map, SHUNT_CAL, ranges, offset, bias, supply and the new `ina228_zvbus_rdiff` are now VERIFIED_LOCAL from the TI datasheet (committed in `docs/rev2/pcb/evidence/`); new entries `tvs_diff` (UV, critical), `esd_connector`, `conn_samtec` (VERIFIED_LOCAL, land pattern), `conn_samtec_key` (UV) | Pulse capability of the 47 Ω / 10 Ω resistors has not been checked against the Panasonic pulse-data document | documents only |
| C4 | `REV2_CALCULATIONS.md` §2b result paragraph rewritten: it said PASS for the defined transient; it now says hot-plug and interruption bounds pass and the protection is **not closed** | the previous wording over-stated closure | documents only |

**Still required before the board is a fabrication candidate** (not done here because the data does not exist yet): see *REMAINING FABRICATION BLOCKERS*. One firmware item belongs to the first article: an INA228 reading outside ±163.84 mV (ADCRANGE 0) or an INA228 / ARM-sense cross-check mismatch must be treated as a sensor fault (load off), because an open Kelvin lead now produces a saturated or garbage shunt reading rather than a hardware failure. No firmware change is made in this round.

**ESD re-evaluation (ERJP08 row of the Panasonic catalog, read locally: 500 V limiting / 1000 V overload; the relayed "125 V / 500 V" does not match it — 125 is the row's terminal temperature in °C).** The existing order *connector → R41–R43 → TVS* makes the resistors carry an ESD pulse. At ±8 kV contact the model puts ≈ 1.3 kV across R41 (≈ 0.37 kV across R42/R43), above the 1000 V overload rating of the 47 Ω part (≈ 0.37 kV on the 10 Ω parts is inside both ratings), and the clamp node at ≈ 79–80 V (85 V limit) before the first-nanosecond overshoot; the ±15 kV air upper bound is ≈ 86–88 V and ≈ 1.9 mJ. The overload rating is a 5 s test, not a pulse rating, so this is not proof of failure — but nothing in the documents supports the event. **Recommendation: if J5/J6 pins can be touched bare, a fast low-capacitance TVS directly at the J5/J6 pins ahead of R41–R43 becomes a required RC1.3 change; if J5/J6 are always mated to a harness inside the enclosure, document that assumption and keep ESD as the first-article test F1.** No board change is made in RC1.2e. Status: `ESD_FIRST_ARTICLE_CONDITIONAL` (see release condition RC-A in X2).

## FIRST-ARTICLE VALIDATION

| # | Test | Pass criterion |
|---|---|---|
| F1 | **ESD at the connectors** (IEC 61000-4-2, target ±8 kV contact / ±15 kV air on J5, J6 pins and shells, stepping 2 → 4 → 8 kV; INA228 and the MCU powered, a read-back of INA228 MANUFACTURER_ID / shunt voltage after every discharge, scope on INA_VBUS and across IN+/IN−) | No reset, no INA228 register upset, no permanent offset shift (> 10 µV at 0 A), resistors intact; if it fails, fall back to a fast connector-level TVS ahead of R41–R43 (RC1.3). Simulation cannot prove the first-nanosecond peak (appendix B4). |
| F2 | Shunt voltage at 0 A with D15 fitted, 25 °C and warm (≈ 60 °C), compared with D15 removed/lifted on a spare board | Offset change ≤ 10 µV (= 4 mA of shunt current) between D15 fitted and lifted; D5/D6/D15 leakage combined, cold and warm |
| F3 | One Kelvin lead open / connected late, 44 V current-limited source, scope across INA_INP − INA_INN and INA_INN to GND | |Vdiff| ≤ 20 V in steady state and during connect; shunt reading goes out of range and the firmware sensor-fault path trips |
| F4 | Hot-plug of the sense harness at 42–44 V with the real harness, 1 µs/div and 10 µs/div | INA_VBUS pin ≤ 60 V, INA_INP/INN pin ≤ 60 V, no step in INA228 calibration after 50 plugs |
| F5 | Resistor stress after F1, F4 and 20 bounce plugs: R41 / R42 / R43 resistance (4-wire) | within ±1 % of initial |
| F6 | J9: plug the FFSD/SWD ribbon on the bench board and check pin 1 (red stripe) against the silk triangle and the shroud key before powering | key slot on the shroud accepts the cable in one orientation only; pin 1 of the cable lands on pad 1 (SWD pinout continuity: pad 1 = VTref, 2 = SWDIO, 4 = SWCLK, 6 = SWO, 10 = NRST) |
| F7 | J5/J6: mate real Molex 22-27-2031/-2041 headers and KK crimp housings before reflow of the production batch: pin diameter / hole fit, pin pitch with a gauge, friction-lock ramp side vs pin 1 | headers seat flat, housings mate in the keyed direction only |
| F8 | IRLML0060 3.3 V gate check and buck input envelope (carried over from RC1.2: first-article, unchanged) | as in `BENCH_V1_V10_ONE_PAGE.pdf` |

## REMAINING FABRICATION BLOCKERS

| # | Blocker (X-numbers; the B-numbers in the appendix are event sections) | What closes it |
|---|---|---|
| X1 | **J5 / J6 (Molex 22-27-2031 / -2041): CLOSED for the mechanical geometry; one residual accepted.** The official Molex 3D model of 22-27-2031 (PRO/E STEP + IGES) and the TraceParts AP242 STEP were read locally: pitch 2.54, square pin 0.64, tail 3.56, body 7.62 × 5.80, friction-lock wall on one long side spanning the pin row — all match the KiCad KK-254 footprints (Fab outline, lock-wall side, silk/courtyard). **Residual (not verifiable from 3D data):** pad 1.74 × 2.19 and drill 1.19 are the KiCad library values (the library cites the Molex sales drawing); plausibility only (pin diagonal 0.905 mm, 0.14 mm per side); the 4-position 22-27-2041 model was not supplied (same series construction, body 10.16 mm). Covered by first-article F7 (mate real headers before the batch). | — |
| X2 | **CONVERTED TO A RELEASE CONDITION — Panasonic ERJ-P08 pulse capability is not published** (AOA0000C331 read locally: ratings + ±3 kV/150 pF ESD test + a warning that pulse loads are the user's to evaluate; no curve). **Release condition RC-A = YES (confirmed by Joe, 2026-10-01): J5 and J6 are internal connectors inside the enclosure, permanently mated to their harnesses inside the enclosure and not user-accessible, so ESD/pulse survival is a first-article test (F1, F5) and **X2 is CLOSED as a fabrication blocker**. If the enclosure/harness design ever exposes bare J5/J6 pins in normal use, reopen X2 and require the RC1.3 connector-side clamp.** Background (figures for reference): Voltage ratings: 500 V limiting / 1000 V overload, read locally from the ERJP08 row of the catalog (two copies); the catalog gives DC ratings and the ±3 kV 150 pF ESD test only — no pulse curve. Event energies per appendix B are ≈ 0.1 mJ per hot-plug, ≤ 0.37 mJ per 18.5 A interruption (gross over-estimate) and ≈ 0.53 mJ for an 8 kV contact ESD pulse into R41 (an upper-bound 15 kV air pulse is ≈ 1.9 mJ) — compared only with the catalog ESD-test energy (0.675 mJ), not with a pulse curve, so the margin for ESD is ≈ 20 % at 8 kV and negative at the 15 kV upper bound. The 47 Ω / 10 Ω values and suffixes stay provisional. | Panasonic pulse-data document AOA0000C331.pdf (single-pulse energy vs duration, repetition). Note: the independent audit and the user's relay quote 125 V / 500 V; the ERJP08 row of the catalog read here says 500 V / 1000 V (125 is the terminal temperature in °C) — unless AOA0000C331.pdf shows otherwise (appendix F) |
| X3 | **D15 (SMF12CA): CLOSED** — Littelfuse SMF datasheet read locally (VRWM 12 V, VBR 13.3–14.7 V, IR ≤ 2.5 µA, IPP 10.1 A, VC 19.9 V, 200 W / 1000 W; mounting pad layout 1.6 / 1.3 × 1.4 mm = the KiCad `D_SMF` pads). Residual, not a blocker: junction capacitance and leakage below 12 V are not in the datasheet (first-article F2); the datasheet names the case SOD-123FL (distributors say SOD-123F); D15 is DNP-capable. | — |
| X4 | INA228 ±40 V differential / 85 V CM and VBUS maxima: **CLOSED** — read from TI SLYS021A §6.1 (committed in the evidence folder). | — |
| X5 | Earlier open items carried unchanged: critical evidence-register entries not yet VERIFIED_LOCAL, STM32 / DG57CM / LMR14006Y items in `EVIDENCE_RISK_CLASSIFICATION.md`; Gerbers are exported by Joe from KiCad 10 after the checks are re-run locally; do not send the RC1.2x ZIPs to PCBWay yet. | see `PRE_PCBWAY_RELEASE_CHECKLIST.md` |

**READY FOR JOE'S LOCAL KICAD 10 EXPORT** (still NOT RELEASED FOR FABRICATION): no blocker remains — X1 closed for the mechanical geometry with the J5/J6 hole/pad residual covered by first-article F7, X2 closed under RC-A = YES, X3 and X4 closed. Open: first-article tests F1–F8 and the owner's local KiCad 10 actions (re-run ERC/DRC, export Gerbers, CAM/CPL review).
---

## Appendix A — network audited

```
J6.1 PACK_INA_CON ─ R41 47 Ω ─ PACK_INA ─┬─ D7 1.5SMBJ48A → GND
                                          └─ R13 10 Ω ─ INA_VBUS ─┬─ C28 100 nF → GND ─ INA228 VBUS
J5.1 SHUNT_INP_CON ─ R42 10 Ω ─ SHUNT_INP_RAW ─┬─ D5 1.5SMBJ48A → GND
                                               └─ R11 10 Ω ─ INA_INP ─┬─ C26 100 nF ─┬─ INA_INN ─ R12 10 Ω ─ SHUNT_INN_RAW ─┬─ D6 → GND
                                                                      └─ D15 SMF12CA ┘ (NEW, bidirectional)                └─ R43 10 Ω ─ SHUNT_INN_CON ─ J5.2
J6.2 PACK_ADC ─ R17 75 k ─ R18 75 k ─ ADC_TAP ─ R19 10 k → GND ; ADC_TAP ─ R20 1 k ─ PA1 (C29 100 nF, D8/D14 BAT54S clamps)
```
Topology evaluated against the alternatives: (a) *connector → R → TVS → filter → VBUS* (existing; right for slow surges, wrong for ESD because the series resistor sits between the connector and the clamp); (b) *symmetric Kelvin network + differential clamp* (adopted: D5/D6 stay, D15 added); (c) *fast low-capacitance ESD diode at the connector ahead of the resistors* (not added now — see appendix B4 and F1; it becomes the RC1.3 fallback if the ESD test fails, because it changes the connector area and needs a part that has not been selected from a datasheet).

## Appendix B — per-event calculations

Common inputs: pack source 44 V, source + harness resistance 0.3 Ω [UV], harness L 0.5/2/5 µH [UV], TVS junction capacitance 0.3/1/3 nF [UV]; 1.5SMBJ48A clamp curve from the Bourns datasheet points (58.9 V knee, 77.4 V at 19.4 A, 100.6 V at 97 A; the straight line between the rating points is an estimate). INA228 limits (TI datasheet §6.1): VBUS / IN± to GND 85 V, IN+ − IN− ±40 V, 5 mA into any pin.

### B1 Hot-plug of the sense harness onto a live 44 V pack

| path | source V | Rs upstream | TVS current (derived from the simulated node, not the 97 A rating) | clamp / node V | INA pin V (CM stress) | energy in Rs |
|---|---|---|---|---|---|---|
| VBUS (R41 47 Ω), no series R (reference) | 44 V | 0 Ω | 0.0 A | 48.3 V | 44.0 V | 0.00 µJ |
| VBUS (R41 47 Ω), worst of 9 L/C combinations | 44 V | 47 Ω | 0.00 A | 43.9 V | 43.9 V | 82.66 µJ |
| Kelvin line (R42/R43 10 Ω), no series R (reference) | 44 V | 0 Ω | 0.9 A | 59.8 V | 59.8 V | 0.00 µJ |
| Kelvin line (R42/R43 10 Ω), worst of 9 L/C combinations | 44 V | 10 Ω | 0.68 A | 59.5 V | 59.5 V | 2.84 µJ |

Result: with R41–R43 fitted the VBUS path never reaches the knee; the Kelvin path rings to 59.5 V (knee 58.9 V, TVS current 0.68 A); INA228 pin peak 59.5 V against 85 V; single-event energy in the resistors ≤ 83 µJ (the VBUS value is the ½·C28·V² = 97 µJ needed to charge C28, independent of R41). **PASS** (model; pulse capability of the resistors OPEN, blocker X2).
Differential stress: the two Kelvin lines rise together only if both leads connect at the same instant; any skew between them is the one-lead-early case of B5. D15 bounds the difference regardless of the cause.

### B2 Contact bounce

Bounce is a train of B1 events. The first closure charges C28 (VBUS path) through R41 + R13: ½·C·V² = 97 µJ, independent of the resistor value. C28 is discharged only by the INA228 VBUS input (ZVBUS ≥ 0.8 MΩ, TI datasheet) and TVS leakage, τ ≈ 80 ms, so during a ≈ 1 ms contact gap it droops by ≈ 0.55 V and each later bounce re-dissipates only ≈ ½·C·ΔV² = 15 nJ. Worst realistic total for one plug-in with 20 bounces ≈ 97 µJ; for deliberate repeated plugging once per second the average power is ≈ 0.10 mW against 660 mW (0.66 W at 70 °C, Panasonic catalog). Kelvin lines charge only ≈ 1 nF of TVS/pin capacitance per line (≈ 1 µJ). **PASS on average power; repetitive/single-pulse capability of the 1206 part = blocker X2.**

### B3 Interruption of load current (K1 opening, fuse clearing, 6060B turn-off), ≤ 18.5 A

The only energy source is the harness inductance carrying the interrupted current. The gross over-estimate forces the whole current into the sense branch (a thin sense harness cannot carry it):

| interrupted current | path | TVS current | clamp V | INA pin V | energy in Rs | resistor V (instant, gross) |
|---|---|---|---|---|---|---|
| 10.0 A | VBUS, Rs = 0 Ω | 3.8 A | 62.5 V | ≤ 62.5 V | 0 µJ | 0 V |
| 10.0 A | VBUS, Rs = 47 Ω | 1.3 A | 60.1 V | ≤ 60.1 V | 142 µJ | 470 V |
| 10.0 A | Kelvin line, Rs = 0 Ω | 10.0 A | 68.4 V | ≤ 68.4 V | 0 µJ | 0 V |
| 10.0 A | Kelvin line, Rs = 10 Ω | 9.4 A | 67.9 V | ≤ 67.9 V | 74 µJ | 100 V |
| 15.0 A | VBUS, Rs = 0 Ω | 8.3 A | 66.8 V | ≤ 66.8 V | 0 µJ | 0 V |
| 15.0 A | VBUS, Rs = 47 Ω | 5.9 A | 64.5 V | ≤ 64.5 V | 259 µJ | 705 V |
| 15.0 A | Kelvin line, Rs = 0 Ω | 14.9 A | 73.1 V | ≤ 73.1 V | 0 µJ | 0 V |
| 15.0 A | Kelvin line, Rs = 10 Ω | 14.3 A | 72.5 V | ≤ 72.5 V | 175 µJ | 150 V |
| 18.5 A | VBUS, Rs = 0 Ω | 11.5 A | 69.9 V | ≤ 69.9 V | 0 µJ | 0 V |
| 18.5 A | VBUS, Rs = 47 Ω | 8.9 A | 67.4 V | ≤ 67.4 V | 371 µJ | 870 V |
| 18.5 A | Kelvin line, Rs = 0 Ω | 18.4 A | 76.4 V | ≤ 76.4 V | 0 µJ | 0 V |
| 18.5 A | Kelvin line, Rs = 10 Ω | 17.7 A | 75.8 V | ≤ 75.8 V | 271 µJ | 185 V |

Without series resistors the clamp at 18.5 A is 76.5 V (margin 8.5 V to 85 V); with them the energy is ≈ ½·L·I² = 342 µJ (2 µH; the integrator gives up to 0.37 mJ in R41 at 18.5 A). The instantaneous R·I of the forced model (870 V on R41) is not a real resistor stress (a sense wire does not carry 18.5 A); the credible resistor stress is the B1 value. Common mode never exceeds the clamp (≤ 77 V < 85 V); differential stress is zero for an interruption that affects both leads equally. **PASS** for the INA228; resistor energy inside the catalog ESD-test energy (0.675 mJ), pulse curve OPEN (X2).

### B4 ESD at the connectors (IEC 61000-4-2, ±8 kV contact / ±15 kV air)

ESD and surge are different: a 30 A, ≈ 1 ns-rise, ≈ 100 ns pulse (4 kV basis I1 16.6 A / I2 9.3 A, ×2 for 8 kV, ed. 2 waveform) into a series resistor placed **between the connector and the clamp** means the resistor carries the pulse and develops its voltage; the TVS behind it only limits the node it protects. The table integrates the standard waveform (scaled for the gun's 330 Ω source into the path resistance instead of the 2 Ω target):

| zapped pin | path R | peak current | pin voltage ≈ V_clamp + I·R | energy in the series R | charge | node after R (clamp at that current) | INA228 pin after R13/R11 |
|---|---|---|---|---|---|---|---|
| PACK_INA (R41 47 Ω), ±4 kV contact | 47 Ω | 13.1 A | 689 V | 0.13 mJ | 0.51 µC | 71 V (estimate [UV]) | ≤ 71 V before C28/C26 filtering [UV] |
| Kelvin IN+ / IN− (R42/R43 10 Ω), ±4 kV contact | 10 Ω | 14.6 A | 218 V | 0.03 mJ | 0.57 µC | 73 V (estimate [UV]) | ≤ 73 V before C28/C26 filtering [UV] |
| PACK_INA (R41 47 Ω), ±8 kV contact | 47 Ω | 26.3 A | 1315 V | 0.53 mJ | 1.03 µC | 79 V (estimate [UV]) | ≤ 79 V before C28/C26 filtering [UV] |
| Kelvin IN+ / IN− (R42/R43 10 Ω), ±8 kV contact | 10 Ω | 29.1 A | 372 V | 0.14 mJ | 1.14 µC | 80 V (estimate [UV]) | ≤ 80 V before C28/C26 filtering [UV] |
| PACK_INA (R41 47 Ω), ±15 kV air (upper bound: contact waveform scaled by voltage; the air-discharge current is not specified by the standard) | 47 Ω | 49.3 A | 2402 V | 1.87 mJ | 1.93 µC | 86 V (estimate [UV]) | ≤ 86 V before C28/C26 filtering [UV] |
| Kelvin IN+ / IN− (R42/R43 10 Ω), ±15 kV air (upper bound: contact waveform scaled by voltage; the air-discharge current is not specified by the standard) | 10 Ω | 54.6 A | 634 V | 0.49 mJ | 2.14 µC | 88 V (estimate [UV]) | ≤ 88 V before C28/C26 filtering [UV] |

Findings: (1) the 8 kV discharge into R41 puts ≈ 1315 V across the pin–resistor–TVS path for tens of ns and ≈ 0.53 mJ into R41 — ≈ 80 % of the resistor's catalog ESD-test energy (0.675 mJ, ±3 kV / 150 pF; a different pulse shape) — little margin; the ERJP08's limiting element voltage is 500 V and its maximum overload voltage 1000 V (catalog row, read locally), so ≈ 1.3 kV across R41 is **above the documented 1000 V overload rating** (R42/R43 at ≈ 0.37 kV are inside it) (a 5 s overload test, not a pulse rating, but no pulse curve supports the event) (X2). (2) The node behind R41 is clamped at ≈ 79 V — 6 V under the INA228 85 V limit **before** the first-nanosecond TVS turn-on overshoot (a few nH of loop inductance × 30 A/ns can add > 100 V for ≈ 1 ns; C28 + R13 attenuate it, but that cannot be shown here). (3) An ESD pulse on one Kelvin pin produces a one-sided ≈ 80 V node. With C26 intact the 100 nF couples it to the other pin and the **differential** stays ≈ 1 % of that (≈ 1 V); if C26 is open, the pulse is a ≈ 80 V difference against the ±40 V limit, and D15 limits it to its clamp level (VC 19.9 V at 10.1 A) plus the R11/R12 drop. (4) PACK_ADC (J6.2) has no clamp ahead of its 160 kΩ chain; 8 kV ESD there peaks at ≈ 50 mA through the resistors and the BAT54S clamps, which is not a surge problem but the 0603 thin-film resistor body voltage is unknown (first-article F1 includes J6.2).

**Conclusion: ESD survival cannot be proven by simulation** (first-nanosecond peak, parasitic inductance, TVS turn-on, resistor-body withstand). It stays a **first-article test (F1)**. If it fails, the likely fix is a fast low-capacitance TVS directly at the J5/J6 pins ahead of R41–R43 (RC1.3) so that the resistors no longer carry the pulse.

### B5 One Kelvin lead early / open / late-connect (the case that needs the differential clamp)

Setup: both leads normally sit at pack potential (≤ 44 V common mode) and differ by ≤ 50 mV. Case A: IN+ lead connected, IN− lead open or not yet plugged. Case B is the mirror (IN− connected, IN+ open: difference −44 V, the limit is ±40 V so it is symmetric).

**What holds the open pin, by regime** (this decides whether D15 is needed):
1. *INA228 powered, C26 intact.* A fast step on IN+ is passed to the open IN− pin by C26 (capacitor divider C26 / (C26 + ≈ 1 nF of D6/pin capacitance) ≈ 99 %), so the **difference is only ≈ 0.4 V** for a 44 V step; afterwards the INA228's differential input path (R_DIFF 92 kΩ typical, **TI datasheet, read locally — specified for active mode with |VIN+ − VIN−| < 164 mV only**) pulls IN− toward IN+ (τ ≈ R_DIFF × 100 nF ≈ 9 ms), leaving only leakage × R_DIFF ≈ 0.1 V per µA. **No hazard in this regime; D15 not needed.**
2. *INA228 unpowered or power-cycling (3V3_A off, or the Kelvin harness plugged before the controller is switched on).* There is no sampling path; the open pin is held only by C26 and leakage to ground (D6 ≤ 1 µA at 48 V, 25 °C; RDIFF is specified for active mode only, so nothing in the datasheet holds the open pin here). The difference then **grows as the leakage discharges the node**; the INA228 would be powered up with up to 44 V across its inputs:

| leakage pulling IN− toward ground | time for the difference to reach 40 V (Q = C26 × 44 V = 4.4 µC) |
|---|---|
| 1000 nA | 4 s |
| 100 nA | 44 s |
| 10 nA | 440 s |
3. *C26 failed open / not fitted / badly derated* (a cracked MLCC is a classic field failure): regime 1 loses its capacitive coupling; a one-sided clamp event (≈ 80 V node, B4) is then a ≈ 80 V difference for its duration (the independent audit gives 60–83 V when the other lead is open; that figure ignores C26, which is why it is regime 3, not regime 1).

**Conclusion on the question "is a differential clamp required?":** not required for a powered INA228 with an intact C26; **recommended as a backstop** for regimes 2 and 3 because the failure it prevents (a destroyed INA228 and an unreadable shunt) is expensive and the cost is one 2-pad part. It stays UNVERIFIED (datasheet not read) and can be left unpopulated without any other change if the INA228 datasheet shows the unpowered input state is safe — the decision-determining datasheet fact is INA228 input behaviour at VS = 0.

**With D15 (bidirectional; Littelfuse datasheet read locally: VRWM 12 V, VBR 13.3–14.7 V at 1 mA, IR ≤ 2.5 µA at 12 V, VC 19.9 V at IPP 10.1 A).** In every regime the difference cannot exceed the D15 clamp; in regime 2 the open node settles where the leakage currents balance, ≈ 5–15 V [UV], far below ±40 V; common mode stays ≤ 44 V (limit 85 V).

| event | source V | series R in the D15 loop | D15 current | difference across IN+/IN− | CM stress | PASS? |
|---|---|---|---|---|---|---|
| late connect of IN+ at 44 V, IN− open — first edge (C26 couples: D15 nearly idle) | 44 V | 20.0 Ω (R42 + R11) | ≤ 1.4 A for ≈ 20 ns (charging D6/pin capacitance) | ≈ 0.4 V with C26 intact; bounded by ≈ 16–20 V either way | ≤ 44 V | yes |
| late connect at 30 V — first edge (C26 couples: D15 nearly idle) | 30 V | 20.0 Ω (R42 + R11) | ≤ 0.7 A for ≈ 20 ns (charging D6/pin capacitance) | ≈ 0.3 V with C26 intact; bounded by ≈ 16–20 V either way | ≤ 30 V | yes |
| IN− lead stays open, steady state | 44 V | — | leakage only (nA–µA) | ≤ ≈ 15 V (clamp) | ≤ 44 V | yes (UV: D15 data) |
| IN− lead plugged in late (while the INA pins sit 15–30 V apart) | 44 V | R43 + R12 (20 Ω) + R42 + R11 (20 Ω) = 40 Ω | ≈ (30 V − 16 V)/40 Ω ≈ 0.35 A for ≈ 4 µs while C26 discharges | falls to 50 mV in ≈ 5 τ = 20 µs | ≤ 44 V | yes |

D15 power (late-connect rows apply when C26 is intact or not; with C26 intact D15 is nearly idle): ≤ 0.35 A × 16 V × 4 µs ≈ 22 µJ per event, far below the SMF12CA ratings (200 W 10/1000 µs, 1000 W 8/20 µs, IPP 10.1 A). **Recovery:** when the lead is reconnected the INA228 pins return to the 50 mV level in ≈ 5τ = 20 µs (Kelvin filter 40 Ω × 100 nF); the INA228 conversion time ≥ 50 µs, so the first conversion after reconnection is already valid.

**Measurement error caused by D15** (normal operation, Vshunt ≤ 50 mV): leakage of D15 below its stand-off voltage is not given by the datasheet; bound using the 12 V stand-off leakage (≤ 2.5 µA) as if it flowed at 50 mV: error = I × (R11 + R42 + R12 + R43 + lead resistance) = 2.5 µA × 40 Ω = 100 µV = 0.4 % of 25 mV (10 A) — a **gross over-estimate**: TVS leakage at 0.4 % of the standoff voltage is orders of magnitude lower (nA-class). It would be a constant additive offset removable by the zero calibration, validated in F2. D15 capacitance (not in the datasheet; SOD-123FL TVS of this size are tens of pF [UV]) is ≪ C26 and does not change the Kelvin filter. **Decision: D15 added as a backstop (see the conclusion above); it is the only RC1.2e change that is a judgement call rather than a measured defect.**

### B6 Reversed wiring (where reasonably protectable)

| mistake | what happens | protectable? |
|---|---|---|
| Kelvin leads swapped (IN+ on the load side) | the shunt voltage is negative (−25 mV at 10 A); INA228 reads a negative current; no overstress (both within ±50 mV, ±163.84 mV range) | not a hazard; firmware sign check at first article |
| Pack polarity reversed at J6 (PACK_INA lead on pack −, GND lead on pack +, −44 V) | D7 conducts forward (≈ −1 V clamp): R41 carries 44 V / 47 Ω = **0.94 A continuous = 41 W** in a 0.66 W resistor (it fails open as a fuse, possibly charring), and the INA228 VBUS pin is driven to ≈ −1 V through R13 (10 Ω): ≈ 50 mA into the pin protection diode (absolute maximum 5 mA per pin — about 10× exceeded; the INA228 abs-min is −0.3 V and the absolute maximum pin current is 5 mA (TI datasheet)) | **not reasonably protectable** on this board without a series blocking element in a 44 V sense line (diode drop and leakage error, parts not selected). Accepted limitation, documented: J6 is a polarized KK header with a labelled harness; verify polarity at the bench before connecting the pack. |
| Pack polarity reversed at J5 (Kelvin) | D5/D6 conduct forward clamping the INA pins at ≈ −1 V; the 20 Ω per line limit the current to ≈ 2 A peak decaying — D15 also conducts (bidirectional, difference ≤ 20 V). Both leads reversed equally leaves the difference at ≈ 50 mV. Abs-min of IN± (−0.3 V) is exceeded for the duration | not reasonably protectable; same limitation |

### B7 Leakage-induced error, filter settling and recovery (normal operation)

| item | value | note |
|---|---|---|
| D5/D6 leakage mismatch × R42/R43 | ≤ 1 µA × 10 Ω = 10 µV = 4 mA-equivalent (0.04 % of 10 A) at 25 °C | Bourns IR ≤ 1.0 µA at 48 V, 25 °C (read locally); temperature dependence not specified [UV] → F2 |
| D7 leakage × R41 | ≤ 1 µA × 47 Ω = 47 µV on 44 V (1.1 ppm) | |
| INA228 bias (2.5 nA max, TI datasheet) × 20 Ω per Kelvin line | ≈ nV, cancels with matched 1 % resistors | |
| D15 leakage × 40 Ω loop | ≤ 100 µV worst-case bound (2.5 µA max at 12 V × 40 Ω = 0.4 % of 25 mV); expected ≪ (leakage at 50 mV is not specified) | F2 |
| VBUS divider error from 57 Ω into the input | ≈ 0.007 % (3 mV at 44 V), fixed ratio, removed by calibration against the EDU34450A | |
| Kelvin filter 2 × 20 Ω + C26 | τ = 4.0 µs, fc 40 kHz; 5τ = 20 µs | INA228 conversion ≥ 50 µs |
| VBUS filter 57 Ω + C28 | τ = 5.7 µs, 5τ = 28 µs | |
| PA1 filter (150 k ∥ 10 k + 1 k) × C29 100 nF | τ = 1.04 ms, 5τ = 5.2 ms | slow by design (cross-check channel) |
| Recovery after a clamp event | ≤ 5τ above: 20–30 µs for the INA228 pins, ≈ 5 ms for PA1 | a transient does not leave the ADC reading stale for longer than one 10 ms logging step |

## Appendix C — PA1 (cross-check channel) min / max

| event | ADC_TAP | PA1 | note |
|---|---|---|---|
| normal, 30 V | 1.875 V | 1.875 V | no current through R20 (1 k) |
| normal, 36 V | 2.250 V | 2.250 V | no current through R20 (1 k) |
| normal, 42 V | 2.625 V | 2.625 V | no current through R20 (1 k) |
| normal, 44 V | 2.750 V | 2.750 V | no current through R20 (1 k) |
| 48 V (above the ceiling, still inside the divider range) | 3.000 V | 3.000 V | |
| overvoltage on PACK_ADC, 100 V | unclamped 6.25 V | ≈ 3.35 V (VCLAMP + Vf of the BAT54S upper diode [UV]) | clamp current ≈ (6.25 − 3.35)/161 kΩ ≈ 0.02 mA through the 75 k + 75 k chain |
| reversed pack −44 V on PACK_ADC | −2.75 V | ≈ −0.3 V (lower BAT54S diode) | injection ≈ (44 − 0.3)/161 kΩ = 0.27 mA, inside the STM32 injection limit [UV] |
| controller unpowered, pack at 44 V | tap 2.75 V | ADC_SENSE → D8 → VCLAMP → R37 (10 k) | 3V3 stays at ≈ 0 V (D14 blocks, R4 bleeder) — design from RC1.1, unchanged |
| PACK_ADC lead open | 0 V | 0 V | INA228 vs ARM-sense cross-check flags a mismatch (firmware) |
| ESD on PACK_ADC | — | clamps conduct | first-article F1; only 160 kΩ in series, no pre-clamp (see B4) |

Leakage: BAT54S reverse leakage into the 9.4 kΩ source impedance is ≈ 0.01 % (RC1.1 calculation); it is not changed by D15. Accuracy of the divider itself is independent of the protection events.

## Appendix D — J9 Samtec FTSH-105-01-L-DV-K verification

| item | Samtec drawing (read locally) | RC1.2d generic footprint | RC1.2e footprint |
|---|---|---|---|
| pitch | 1.27 × 1.27 mm | 1.27 | 1.27 |
| pad size | 0.74 × 2.79 mm (rec. layout rev H, sheet 1) | 0.74 × 2.40 | 0.74 × 2.79 |
| pad span (overall) | 0.270 in = 6.86 mm | 6.30 mm | 6.86 mm |
| row spacing (centre to centre) | 6.86 − 2.79 = 4.07 mm (gap between rows 1.28 mm) | 3.90 mm | 4.07 mm |
| locating hole 'A' (table 1) | -K: N/A (no PCB hole) | none | none |
| body | 5 × 1.27 = 6.35 mm long (+0.13/−0.36), 3.43 mm wide, tail-to-tail 5.84 mm (product drawing rev FX) | — | Fab outline 6.35 × 3.43; courtyard 7.4 × 6.9 mm |
| pin numbering | pin 01 bottom-left, 02 directly above, 03 to the right of 01 (drawing view) | pin 1 top-left, 2 top-right, 3 below pin 1 | same as the generic frame; rotating the footprint +90° (CCW) gives the Samtec view, same handedness (no mirror) |
| key | -K = keying part FTSH-50-CN-xx in the shroud, centred on the shroud, positions 05–25, lead style -01 only | not keyed | **side not resolved by the drawings** → F6 |

On the board J9 sits at (160, 140) with rotation 0: pin 1 top-left (silk triangle + "1" at the left of pad 1), pad 2 top-right, rows running along y. The SWD cable plugs vertically from the top; its pin 1 (red stripe) goes to the triangle. Checked: courtyard does not overlap any neighbour (DRC), pads clear the GND pour by the 0.25 mm rule, J9's silk is two short bars outside the pad rows (no silk over pads). Pad-to-neighbour clearance fixed by moving two traces into the 1.28 mm row gap. **J9 land pattern: CLOSED. Key side: first-article F6.**

## Appendix E — J5 / J6 Molex status

What was supplied and read: the official Molex 3D model of 22-27-2031 (PRO/E STEP, IGES; `calc/molex_igs_check.py` prints the extracted geometry), the TraceParts AP242 STEP of the same part, the product specification PS-99020-0088-001 (0.64 mm square pin headers; no PCB hole data), and several product pages / 3D-picture drawings of 22-27-2041 without dimensions. **Result (J5):** pins at x = 0, ±2.54 (pitch 2.54), square pin 0.64 mm, tail end 3.56 mm below the seating plane, body 7.62 × 5.80 mm (STEP; IGES control points reach 7.92 × 6.03), a friction-lock wall on one long side only, spanning the pin row (±2.64 mm) and rising to ≈ 9.5 mm. The KiCad footprint has the same pitch, Fab outline 7.62 × 5.80, a silk envelope of 7.84 × 6.02 and the lock wall drawn on one side. **Not in the 3D data:** the PCB hole and pad (footprint drill 1.19 / pad 1.74 × 2.19 are KiCad library values citing Molex sales drawing 022272021_sd.pdf; plausible against the 0.905 mm pin diagonal) and the 4-position 22-27-2041 model (same series; body 10.16 mm). **J5/J6: mechanical geometry CLOSED; pad/drill residual covered by first-article F7.** No board change.

## Appendix F — cross-reference to the independent audit on this branch (`audit/CONTROLLER_AUDIT_REPORT.md`, written by a separate session)

That session had the INA228 datasheet and the Panasonic ERJP08 sheet AOA0000C331.pdf. **The INA228 datasheet has since reached this session and was read locally (rows below marked accordingly)**; the Panasonic and Littelfuse values remain `USER_RELAYED_MANUFACTURER` until those PDFs are committed and read. What that audit reports, and how it compares:

| item | independent audit (from the PDFs it had) | this audit | consequence |
|---|---|---|---|
| INA228 absolute maxima | VBUS/VCM −0.3…85 V, differential ±40 V, 5 mA into any pin, HBM ±2 kV | **read locally from TI SLYS021A §6.1**: differential ±40 V, CM and VBUS −0.3…85 V, VS 6 V, 5 mA into any pin, HBM ±2 kV / CDM ±1 kV | **agree and closed (VERIFIED_LOCAL)** |
| INA228 R_DIFF, Z_VBUS, bias | R_DIFF 92 kΩ, Z_VBUS 0.8/1/1.2 MΩ, I_B 0.1/2.5 nA | same values read locally; R_DIFF is specified for active mode (|VIN+ − VIN−| < 164 mV) only | VBUS gain error 0.0071 % with 0.8 MΩ (calibrated out); R_DIFF holds an open pin only while the INA228 is active (B5 regime 1), which is why D15 stays as a backstop for unpowered / shutdown / C26-open |
| Panasonic ERJP08 voltage ratings | limiting element voltage 125 V, maximum overload 500 V | **500 V limiting / 1000 V overload** — now confirmed in AOA0000C331 itself (29-Sep-23 copy, read locally) and in the earlier catalogs; the 125 in the row is the rated terminal-part temperature, °C | **corrected**: ≈ 1.3 kV across R41 at 8 kV contact is still above the 1000 V overload rating; R42/R43 inside; AOA0000C331 has no pulse curve, so ESD is decided by RC-A / first article |
| One-sided event with the other lead open | 60–83 V differential (IN− held only by R_DIFF) | ≈ 1 % with C26 intact (B4, B5), ≈ 80 V if C26 is open | different conclusion because that audit does not include the 100 nF C26 across the pins; D15 covers the C26-open and INA-unpowered cases |
| ESD at the INA pin | 8 kV: 77.9 V; 15 kV air: 83.4 V (87.0 V at +60 K) | 8 kV: 79 V; 15 kV air (upper bound): 86 V | agree: no margin at 15 kV air, and the first-nanosecond spike is not resolved by either model |
| Lower-clamp TVS | suggests 1.5SMBJ45A (clamp ≈ 5–6 V lower, but only 1 V standoff headroom over 44 V and higher leakage) | not adopted | evaluate only after the ESD decision; the headroom is thin |
| Samtec J9 / Molex J5, J6 | land pattern not available (J9 "likely wrong"); Molex PDFs missing | J9 replaced from the rev-H land pattern; Molex J5/J6 mechanical geometry verified from the official Molex 22-27-2031 3D model (STEP/IGES + TraceParts STEP), pad/drill residual covered by F7 | consistent; both items flagged by that audit are closed in RC1.2e |
## Appendix G — what was and was not changed

**Post-freeze fix (found by Joe's first local KiCad 10 run):** the generated PCB carried plain net names while the schematic names sheet-local nets '/<sheet>/NAME' and lacked the symbol fields, so 'Update PCB from Schematic' renamed the nets under the tracks (≈ 1370 DRC violations, 270 unconnected). `design/parity.py` now gives the PCB exactly the schematic's net names (incl. `unconnected-(...)`), the symbol fields, and the netclass patterns / isolation check match both name forms; the DRC report now includes KiCad's schematic-parity test (0 violations) and the netlist check compares exact names. No geometry changed. Changed: J9 footprint (+ J9 breakout routing), D15 + 4 vias on INA_INP/INA_INN, evidence register, calculation text, this report, checklist/risk/connector documents. **Not changed:** every other footprint and track, the isolation geometry and rules, netclasses, BOM except one added line (D15 SMF12CA), the Pi/display branch (untouched).

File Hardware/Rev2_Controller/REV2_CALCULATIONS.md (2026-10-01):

# OSBAMS Rev.2 controller — calculations (RC1, generated)

Generated by `calc/rev2_calcs.py` from `calc/datasheet_inputs.json`. Evidence tags: none = VERIFIED_LOCAL, **[UR]** = USER_RELAYED_MANUFACTURER, **[UV]** = UNVERIFIED. RC1 is a review candidate: **NOT FOR FABRICATION** until the critical entries are VERIFIED_LOCAL.

## 1. Independent ADC channel

`PACK_ADC -> 75k -> 75k -> ADC_TAP -> 10k -> GND`; `ADC_TAP -> 1 k -> ADC_SENSE (PA1) + 100 nF`; clamps D8/D14 (below).

| Vpack | ADC_TAP |
|---|---|
| 30 V | 1.875 V |
| 36 V | 2.250 V |
| 42 V | 2.625 V |
| 44 V | 2.750 V |
| 48 V | 3.000 V |

Ratio 16:1; 12-bit LSB 0.806 mV = 12.9 mV at the pack; divider 275 µA / 12.1 mW at 44 V (5.7 mW per 75 kΩ); source impedance 9.38 kΩ + 1 kΩ; τ ≈ 1.04 ms.

**Error budget — three separate groups:**

| Group | Item | Worst case |
|---|---|---|
| A divider | 0.1 % resistors | ±0.19 % |
| A divider | 25 ppm/K, 40 K excursion | ±0.20 % |
| A divider | clamp leakage (≈0.4 mV, BAT54S [UV]) | ±0.04 % |
| **A subtotal** | | **±0.43 %** |
| B ADC | TUE 4.0 LSB [UV] | ±0.10 % |
| C reference | VDDA 3.3 V ± 2 % (uncorrected) | ±2.00 % |
| C reference | after VREFINT correction [UV] | ±0.30 % |

Total uncorrected ±2.53 % (±1.11 V at 44 V); VREFINT-corrected ±0.83 % (±0.36 V). **Only ±0.43 % is the divider**; the rest is the 3V3 reference, removed by the VREFINT correction. Plausibility cross-check against the INA228 (firmware window 1.5 V), not metrology.

### 1.1 Protection analysis (no back-feed into 3V3)

Circuit: **D8 (BAT54S)** lower diode ADC_SENSE→GND; upper diode ADC_SENSE→**VCLAMP**; **D14** 3V3→VCLAMP blocks the reverse direction; **R37 10 kΩ + C34** bleed VCLAMP; **R4 3.3 kΩ** permanently bleeds 3V3_A. The ADC node has **no direct connection to 3V3**.

| Case | Result |
|---|---|
| Controller powered, pack powered (44 V) | tap 2.750 V; VCLAMP ≈ 3V3 − D14 drop ≈ 3.1 V → upper diode reverse-biased by ≈ 0.35 V, leakage ≈ 100 nA × 9.4 kΩ = 0.94 mV (0.034 %). PA1 max = 2.75 V (48 V: 3.00 V) |
| **Controller unpowered, pack powered** | tap would be 2.75 V; clamp short-circuit current ≤ 0.21 mA flows ADC_SENSE→D8→VCLAMP→R37 (VCLAMP ≈ 2.1 V). D14 is reverse-biased, so **3V3 receives only D14 leakage (nA)**; with R4 on 3V3_A the 3V3 rail stays at ≈ 0 V. |
| Controller unpowered, MCU pin has an internal diode to VDDA (unknown: PA1 (pin 15) FT_la, ADC12_IN6 - NOT 5 V tolerant while the analog switch is connected (diode to VDDA/VREF+); PC10 (pin 51) FT_l [UR]) | worst case ≤ 0.21 mA into 3V3_A; R4 3.3 kΩ limits the rail to 0.68 V < POR min 1.6 V [UV] → the MCU cannot partially power up. Cost: 1 mA permanent load. |
| Reversed pack (−44 V) | tap −2.75 V; D8 lower diode clamps ADC_SENSE at ≈ −0.25 V [UV] (≥ −0.3 V abs min); clamp current 0.27 mA |
| Transient on PACK_ADC to 77.4 V (TVS clamp level) | unclamped tap 4.84 V; upper diode → VCLAMP limits ADC_SENSE to ≈ VCLAMP + 0.25 V ≈ 3.35 V; clamp current ≈ (4.84−3.35)/1 kΩ... limited to 1.49 mA through R20 |

Maximum PA1 voltage: 2.75 V (44 V), 3.35 V (clamped). All diode/pin values are UNVERIFIED and listed as fabrication gates.

## 2. INA228 + Bourns RSA-20-50 (2.5 mΩ, 20 A / 50 mV)

RSA-20-50: ±0.25 % tolerance, ±15 ppm/°C, continuous ≤ 13.3 A (2/3 rated) [UR]. The OSBAMS ceiling (10 A) is below that.

| I | Vshunt | P shunt |
|---|---|---|
| 1 A | 2.50 mV | 0.003 W |
| 7.14 A | 17.85 mV | 0.127 W |
| 10 A | 25.00 mV | 0.250 W |
| 13.3 A | 33.25 mV | 0.442 W |
| 15 A | 37.50 mV | 0.562 W |
| 18.5 A | 46.25 mV | 0.856 W |
| 20 A | 50.00 mV | 1.000 W |

**ADCRANGE = 0 (±163.84 mV)**: range 1 (±40.96 mV = ±16.38 A) would saturate before the 18.5 A firmware trip (46.25 mV).
- IMAX = 20 A: CURRENT_LSB = 38.147 µA, **SHUNT_CAL = 1250** (limit 32767; equation). Current firmware header still uses 30 A / 1875 → firmware change.
- Offset ±1 µV → 0.40 mA = 0.0040 % of 10 A. Native current LSB 125 µA (range 0).
- Input filter 2 × 10 Ω + 100 nF: fc = 80 kHz; bias 2 nA × 10 Ω = 25 nV.
- VBUS: own lead PACK_INA through 10 Ω (error 10 Ω / 0.8 MΩ min ≈ 0.0013 %, ZVBUS 0.8–1.2 MΩ from the TI datasheet) + TVS; common-mode / VBUS range -0.3 to +85 V. **TVS clamp vs the 85 V limit is NOT a single-number comparison — see §2b.**
- INA228 DGS-10 pin map: symbol compared pin-for-pin with the relayed TI table → **PASS** (1 A1, 2 A0, 3 ALERT, 4 SDA, 5 SCL, 6 VS, 7 GND, 8 VBUS, 9 IN−, 10 IN+). Firmware: IMAX 20 A / SHUNT_CAL 1250 (`app_config.h`; the Rev.1 30 A / 1875 setting is retired).

### 2b. Pack-sense protection: 1.5SMBJ48A + surge-limiting series resistors vs the INA228 85 V absolute maximum

**Manufacturer points:** VRWM 48 V, VBR 53.3-58.9 V; VC ≤ 77.4 V at 19.4 A (10/1000 µs) and ≤ 100.6 V at 97 A (8/20 µs). INA228 IN+/IN−/VBUS absolute maximum -0.3 to +85 V. '77.4 V < 85 V' is **not** used as a blanket pass: the clamp exceeds 85 V above ≈ 45 A (straight line between the two rating points = engineering estimate [UV], not a datasheet curve).

**RC1.2 hardware change:** series surge-limiting resistors **upstream of the TVS**: R41 47 Ω on PACK_INA (J6.1 → R41 → D7/R13) and R42/R43 10 Ω on each Kelvin line (J5 → R42/R43 → D5/D6 + the existing 10 Ω R11/R12 → INA228). 1206 anti-surge parts (Panasonic ERJ-P08F series, pulse rating to be confirmed from the datasheet [UV]).

**Credible transient definition for this bench system** (30-42 V pack, 44 V ceiling, ≤ 10 A operating, 18.5 A firmware trip, 15 A fuse, short harness, K1 = Durakool DG57CM):
1. *Interruption of load current (K1 opening, fuse clearing, 6060B turn-off):* the only energy that can force a current into the sense TVS is the inductance of the wiring carrying the interrupted current, ≤ the 18.5 A firmware trip (15 A fuse rating, 10 A operating). The pack cannot push current into a TVS that is clamping above the pack voltage (clamp ≥ 53 V > 44 V). **Bound: TVS current ≤ 18.5 A → VC ≤ ≈76.5 V (rating: ≤ 77.4 V at 19.4 A).** The contact arc appears as a *drop* between the contacts, not as an overvoltage on the sense nodes; a hard downstream short that clears the fuse collapses the sense nodes toward 0 V.
2. *Hot-plug of the sense harness onto a live 44 V pack:* LC ringing, simulated below.
3. *Electrostatic/handling events and mains-borne surges are not part of this bench's credible set;* the series resistors extend the margin toward them (table below) but protection against them is not claimed.

**Hot-plug simulation** (44 V step; source ESR + harness 0.3 Ω; harness L 0.5/2/5 µH; TVS junction C 0.3/1/3 nF [UV]; peak INA-pin voltage is the pin side of the 10 Ω):

| path | Rs upstream | L | C_tvs | TVS peak current | node peak V | INA pin peak V | energy in Rs |
|---|---|---|---|---|---|---|---|
| VBUS path | 0 Ω | 0.5 µH | 1.0 nF | 0.00 A | 44.7 V | 43.9 V | 0.00 µJ |
| VBUS path | 0 Ω | 2.0 µH | 1.0 nF | 0.00 A | 48.3 V | 44.0 V | 0.00 µJ |
| VBUS path | 0 Ω | 5.0 µH | 1.0 nF | 0.00 A | 52.5 V | 45.6 V | 0.00 µJ |
| VBUS path | 47 Ω | 0.5 µH | 1.0 nF | 0.00 A | 43.9 V | 43.9 V | 80.48 µJ |
| VBUS path | 47 Ω | 2.0 µH | 1.0 nF | 0.00 A | 43.9 V | 43.9 V | 80.47 µJ |
| VBUS path | 47 Ω | 5.0 µH | 1.0 nF | 0.00 A | 43.9 V | 43.9 V | 80.47 µJ |
| Kelvin line | 0 Ω | 0.5 µH | 1.0 nF | 1.72 A | 60.5 V | 60.5 V | 0.00 µJ |
| Kelvin line | 0 Ω | 2.0 µH | 1.0 nF | 0.89 A | 59.8 V | 59.8 V | 0.00 µJ |
| Kelvin line | 0 Ω | 5.0 µH | 1.0 nF | 0.57 A | 59.4 V | 59.4 V | 0.00 µJ |
| Kelvin line | 10 Ω | 0.5 µH | 1.0 nF | 0.63 A | 59.5 V | 59.5 V | 0.86 µJ |
| Kelvin line | 10 Ω | 2.0 µH | 1.0 nF | 0.62 A | 59.5 V | 59.5 V | 0.63 µJ |
| Kelvin line | 10 Ω | 5.0 µH | 1.0 nF | 0.46 A | 59.3 V | 59.3 V | 0.49 µJ |

Worst hot-plug case over all combinations **with the resistors fitted**: TVS current 0.68 A, node 59.5 V, INA pin 59.5 V (limit 85 V).

**Forced-interruption bound** (the whole interrupted current is assumed to be forced through the sense branch — a gross over-estimate, since the sense harness is a thin wire):

| interrupted current | L | path | TVS peak current | node peak V | energy in Rs |
|---|---|---|---|---|---|
| 10.0 A | 2 µH | VBUS path, Rs = 0 Ω | 3.8 A | 62.5 V | 0 µJ |
| 10.0 A | 2 µH | VBUS path, Rs = 47 Ω | 1.3 A | 60.1 V | 142 µJ |
| 10.0 A | 2 µH | Kelvin line, Rs = 0 Ω | 10.0 A | 68.4 V | 0 µJ |
| 10.0 A | 2 µH | Kelvin line, Rs = 10 Ω | 9.4 A | 67.9 V | 74 µJ |
| 15.0 A | 2 µH | VBUS path, Rs = 0 Ω | 8.3 A | 66.8 V | 0 µJ |
| 15.0 A | 2 µH | VBUS path, Rs = 47 Ω | 5.9 A | 64.5 V | 259 µJ |
| 15.0 A | 2 µH | Kelvin line, Rs = 0 Ω | 14.9 A | 73.1 V | 0 µJ |
| 15.0 A | 2 µH | Kelvin line, Rs = 10 Ω | 14.3 A | 72.5 V | 175 µJ |
| 18.5 A | 2 µH | VBUS path, Rs = 0 Ω | 11.5 A | 69.9 V | 0 µJ |
| 18.5 A | 2 µH | VBUS path, Rs = 47 Ω | 8.9 A | 67.4 V | 371 µJ |
| 18.5 A | 2 µH | Kelvin line, Rs = 0 Ω | 18.4 A | 76.4 V | 0 µJ |
| 18.5 A | 2 µH | Kelvin line, Rs = 10 Ω | 17.7 A | 75.8 V | 271 µJ |

With Rs = 0 the clamp at the 18.5 A bound is 76.5 V (margin 8.5 V); with the series resistors the interrupted current is dissipated mainly in Rs (≤ ½·L·I² = 342 µJ for 2 µH at 18.5 A — far inside a 1206 anti-surge resistor) and the TVS current is far below 18.5 A.

**Model results only — NOT validated design limits** (open-circuit surge, 8/20 µs, source impedance 2 Ω; TVS current solved against the clamp curve; resistor energy ≈ I²·R·13 µs [UV]; the credible set above is ≤ 100 V-class, i.e. ≤ 1.3 mJ in R42/R43 and ≤ 0.4 mJ in R41):

| Voc | Rs | TVS current | VC (INA node) | within 85 V? | energy in Rs |
|---|---|---|---|---|---|
| 100 V | 0 Ω | 13.9 A | 72.2 V | yes | 0.0 mJ |
| 300 V | 0 Ω | 99.3 A | 101.3 V | **no** | 0.0 mJ |
| 600 V | 0 Ω | 229.8 A | 140.3 V | **no** | 0.0 mJ |
| 1000 V | 0 Ω | 403.8 A | 192.3 V | **no** | 0.0 mJ |
| 2000 V | 0 Ω | 838.8 A | 322.4 V | **no** | 0.0 mJ |
| 100 V | 10 Ω | 3.2 A | 61.9 V | yes | 1.3 mJ |
| 300 V | 10 Ω | 18.6 A | 76.6 V | yes | 45.0 mJ |
| 600 V | 10 Ω | 43.0 A | 84.4 V | yes | 240.0 mJ |
| 1000 V | 10 Ω | 75.5 A | 94.2 V | **no** | 740.8 mJ |
| 2000 V | 10 Ω | 156.8 A | 118.5 V | **no** | 3196.0 mJ |
| 100 V | 47 Ω | 0.8 A | 59.7 V | yes | 0.4 mJ |
| 300 V | 47 Ω | 4.8 A | 63.5 V | yes | 14.2 mJ |
| 600 V | 47 Ω | 10.8 A | 69.2 V | yes | 71.7 mJ |
| 1000 V | 47 Ω | 18.8 A | 76.9 V | yes | 216.9 mJ |
| 2000 V | 47 Ω | 39.1 A | 83.3 V | yes | 934.9 mJ |

These rows are **model results**: the clamp curve is a straight line between two rating points [UV], the waveform is assumed, the 1.5SMBJ48A dynamic impedance and the ERJ-P08F pulse rating have not been read from the datasheets. **No 600 V / 2 kV protection limit is claimed.**

**Measurement-error budget of the new resistors:**
- INA228 input bias 2.5 nA × 20 Ω per Kelvin line = 50 nV worst case unmatched (20 µA of shunt-current equivalent); with matched 1 % resistors the common component cancels (< 1 pV difference) — negligible vs the ±1 µV offset.
- TVS leakage drops across R42/R43 (10 Ω each): up to 1 µA [UV; leakage not relayed] × 10 Ω = 10 µV worst-case line-to-line mismatch = 4 mA of shunt-current equivalent (0.04 % at 10 A; 0.4 mA for a typical 0.1 µA). This is the price of the Kelvin resistors and is why they are 10 Ω rather than 47 Ω; it is removed by the no-load zero calibration only if leakage is stable — verify at first article (shunt voltage at 0 A, 25 °C and warm).
- VBUS: 47 Ω + 10 Ω = 57 Ω into the INA228 VBUS input (ZVBUS ≥ 0.8 MΩ, TI datasheet) → ≤ 0.0071 % gain error (3 mV at 44 V), a fixed ratio that the VBUS calibration against the EDU34450A removes; TVS leakage 1 µA × 57 Ω = 57 µV (1.3 ppm).
- Filtering: differential Kelvin filter = 2 × 20 Ω with C26 100 nF → fc ≈ 40 kHz (τ 4 µs ≪ the INA228 conversion time ≥ 50 µs → no effect on logging or the ALERT latency); VBUS: 57 Ω with C28 100 nF → fc ≈ 28 kHz.
- Common mode: both Kelvin lines carry identical series resistance, so the common-mode level (≤ 44 V, limit 85 V) and the bias-current common-mode shift cancel; the TVS pair clamps each line to ground, so a one-sided transient is limited to the TVS clamp (INA228 IN+/IN− differential absolute maximum ±40 V (TI datasheet, read locally): a one-Kelvin-lead-open / late-connect fault is NOT limited by these two ground clamps — the bidirectional clamp D15 across the INA228 pins limits it, see CONTROLLER_PROTECTION_AND_CONNECTOR_AUDIT.md).
- Normal 44 V operation: VRWM 48 V > 44 V and VBR min 53.3 V > 44 V (no conduction); resistor dissipation at DC ≈ 0 (bias/leakage only); 1206 working voltage ≫ 44 V [UV].

**Recomputed values for the defined transient (model; source values marked [UV] are unverified):**
- Resistor pulse energy: forced interruption at 18.5 A / 2 µH: R41 371 µJ, R42/R43 271 µJ (= ½·L·I² = 342 µJ upper bound); hot-plug into the 100 nF on VBUS: R41 ≤ 83 µJ. **Panasonic ERJ P/PA/PM catalog (read locally, ERJP08 1206): 0.66 W at 70 °C, limiting element voltage 500 V, maximum overload voltage 1000 V (ERJP08 row, re-read in the later series catalog; a relayed '125 V / 500 V' appears to be the 125 °C terminal temperature misread), ESD test ±3 kV with 150 pF (= 0.675 mJ). The credible-set energies above (≤ 0.37 mJ, itself a gross over-estimate) are below that ESD-test energy; the catalog gives no µs–ms pulse-energy-vs-duration curve [UV], so the thermal-pulse rating is not documented.**
- PACK_INA error from TVS leakage × 47 Ω: 47 µV per µA of leakage (1.1 ppm of 44 V per µA). **Bourns datasheet (read locally): IR ≤ 1.0 µA at VRWM = 48 V, 25 °C → ≤ 47 µV (1.1 ppm) at 25 °C.** Leakage at 44 V is lower but no curve is given, and leakage vs temperature is **not specified** [UV]; even 10 µA hot would give only 0.47 mV (11 ppm).
- Shunt-offset error from leakage × 10 Ω: 10 µV per µA of mismatch = 4 mA of shunt-current equivalent per µA. **At 25 °C the datasheet bound (IR ≤ 1.0 µA each, so mismatch ≤ 1 µA) gives ≤ 10 µV = ≤ 4 mA (0.04 % at 10 A).** Hot leakage is not specified [UV]: a figure ≥ 5 µA would give ≥ 20 mA — measured at first article (shunt voltage at 0 A, cold and warm).
- Continuous dissipation: R41 carries the VBUS input current (≈ 53 µA at 44 V [UV]) plus leakage: (55 µA)² × 47 Ω ≈ 0.14 µW; R42/R43 carry only bias/leakage (≪ 1 µW) — against the 0.66 W (70 °C) rating of the ERJP08 this is irrelevant.
- Resistor voltage: in the credible set (open-circuit surge ≤ 100 V, 2 Ω source) R41 sees ≈ 39 V and R42/R43 ≈ 32 V for microseconds; the forced-interruption rows above are a gross over-estimate (a thin sense harness cannot carry 18.5 A) and their instantaneous R·I (> 800 V on 47 Ω) must not be read as a resistor stress. The ERJP08 limiting element voltage is 500 V and the maximum overload voltage 1000 V (Panasonic catalog, read locally): the credible-set R42/R43 voltages are inside both, the forced-interruption R·I instants are not real stresses, and the ≈ 1.3 kV an 8 kV ESD pulse puts across R41 (CONTROLLER_PROTECTION_AND_CONNECTOR_AUDIT.md) is above the 1000 V overload voltage — ESD protection is OPEN.
- Temperature: the Bourns typical VBR temperature coefficient is 0.1 %/K; VBR(min) = 53.3 V → 49.8 V at −40 °C (still > 44 V, no conduction) and 56.5 V at +85 °C. If the clamp voltage scales with VBR [UV], the 18.5 A bound rises to ≈ 81.1 V at TA = 85 °C (margin 3.9 V) and ≈ 77.7 V at 40 °C — the margin shrinks with temperature but stays positive for the defined transient; the 19.4 A rating point itself would reach ≈ 82.0 V at 85 °C.
- Worst-case INA228 node voltage in the defined transient: **76.5 V** (forced-interruption bound, Rs = 0, worst-case clamp knee 58.9 V → 77.4 V at 19.4 A) and ≤ 59.5 V in the hot-plug simulation; limit 85 V.

**Result (RC1.2e): hot-plug and interruption bounds PASS against the 85 V limit using datasheet-verified Bourns 1.5SMBJ48A data; the protection is NOT closed.** Open: (1) the resistors' µs–ms pulse-energy rating (Panasonic pulse-data document AOA0000C331.pdf not checked; the 47 Ω / 10 Ω values are provisional until it is), (2) TVS leakage vs temperature and below 48 V, (3) the clamp curve between the two Bourns rating points is an estimate, (4) the one-Kelvin-lead-open case needs the differential clamp D15 (SMF12CA, datasheet not read) and (5) ESD at the connectors is a first-article test (R41–R43 sit upstream of the TVS, so they carry the ESD current). All per-event tables are in CONTROLLER_PROTECTION_AND_CONNECTOR_AUDIT.md. A lower-voltage TVS is rejected (standoff/leakage vs the 44 V ceiling).

## 3. Buck LMR14006Y: 12 V → 3.3 V

Feedback: VREF 0.765 V [UR], R1 33.2 kΩ / R2 10 kΩ → Vout = 0.765 × (1 + R1/R2) = **3.305 V** (1 % resistors: +0.031 V, ±VREF tolerance UV). fsw 2.1 MHz [UR].

Output range with VFB 0.747-0.782 V [UR] and 1 % resistors: **3.178 - 3.431 V** (nominal 3.305 V); the 3V3 rail therefore may sit up to +0.13 V / -0.12 V from 3.30 V (STM32/INA228/ISO7721 supply limits 3.6 V / 5.5 V: within, but the STM32 VDD max is [UV]).

Minimum on-time: **TON_MIN = 95 ns** [UR]; fsw 1.785 / 2.100 / 2.415 MHz (min/typ/max) [UR]. On-time = Vout / (Vin · fsw) (on-time is shortest at the **highest** fsw).

| Vin | duty (typ) | on-time @ typ fsw | on-time @ max fsw | vs 95 ns | ΔIL (L = 10 µH) | Ipk @ 150 mA |
|---|---|---|---|---|---|---|
| 11.0 V | 30.0 % | 143 ns | 124 ns | PASS | 110 mA | 205 mA |
| 12.0 V | 27.5 % | 131 ns | 114 ns | PASS | 114 mA | 207 mA |
| 12.5 V | 26.4 % | 126 ns | 109 ns | PASS | 116 mA | 208 mA |
| 15.0 V | 22.0 % | 105 ns | 91 ns | MARGINAL (typ ok, max-fsw corner below) | 123 mA | 211 mA |
| 24.4 V | 13.5 % | 64 ns | 56 ns | **BELOW TON_MIN: pulse skipping** | 136 mA | 218 mA |

**Corrected statement:** 12 V (normal XDR operation) PASSES (114 ns at the fastest fsw corner). The 15 V corner is only ≈ 10 ns above TON_MIN at typical fsw and is **91 ns (below 95 ns) at the maximum-fsw corner** — not guaranteed fixed-frequency. The **24.4 V SMBJ15A-clamp transient (64 ns) is below TON_MIN: fixed-frequency regulation is NOT claimed there.** Expected behaviour is pulse skipping (fewer, minimum-width pulses; output ripple/frequency change); the datasheet behaviour in this region is not characterised in the data I hold [UV], so no regulation guarantee is made during the transient. The normal source is the XDR at 12.0 V, so this does not invalidate the part; it limits the claim to ≤ ≈ 14.4 V (max-fsw corner) / ≈ 16.6 V (typical fsw) steady-state input. Verify by measurement at first article.

**Design requirement (RC1.2):** XDR-75-12 nominal output = **12.0 V ±1 %** (11.88-12.12 V at the J1 connector; ≈ 11.5-11.7 V at the buck after F1 and D2). **Maximum allowed *continuous* controller input = 14.4 V** (fixed-frequency regulation guaranteed with TON_MIN 95 ns at the fastest fsw corner); the 12 V supply therefore has 2.3 V of headroom. Operation above 14.4 V is not claimed to be fixed-frequency; the SMBJ15A transient (24.4 V clamp) is treated separately below, not as continuous operation.

**3V3 during the 24.4 V transient (TON_MIN-limited pulse skipping):** one minimum-width pulse raises the inductor current by ΔI = (24.4 − 3.30) V × 95 ns / 10 µH = 200 mA, i.e. at most ½LΔI² = 201 nJ per pulse; into ≈ 26 µF of derated output capacitance that is ≤ 2.3 mV per pulse if the load took nothing, and the feedback comparator skips the following pulses, so the rail is regulated by pulse skipping rather than rising. Rail excursion during the transient is therefore millivolts, ≪ the 3.6 V class limit of the loads (STM32/INA228/ISO7721 VDD maximum values are [UV] — confirm 3.6 V-class or higher). A fault in the feedback divider (R1 short / R2 open) is a separate single-fault case that no buck design here protects against.

VIN rating: recommended 4-40 V, absolute max 45 V [UR]; SMBJ15A clamp 24.4 V (+ a 12 V XDR) → margin to 45 V ≈ 20.6 V. 
Inductor/limits (TI): current limit ≈ 1.2 A typ, max duty ≈ 97 %. 
Inductor: Bourns SRN6045TA-100M (10 µH ±20 %, DCR 52 mΩ typ, Irms 3.20 A typ, Isat 4.60 A typ): Isat is ≈ 3.8× the 1.2 A typical current limit and ≈ 20× the ≈ 0.22 A peak load current → closed (typical values). Output 2 × 22 µF 10 V 0805 (≈ 50 % DC-bias derating → ≈ 26 µF): ripple ≈ ΔIL/(8 f C) = 0.26 mV + ESR term. Input C1+C2 2 × 10 µF 50 V 1210 + 100 nF at the VIN pin: ripple ≈ I·D(1−D)/(f C) = 2.4 mV at 6 µF effective.
Surge: SMBJ15A clamp 24.4 V [UR] vs LMR14006Y 40 V rating (margin ≈ 15.6 V; abs-max UV). EN: 100 kΩ to +12V (method [UV]).

3V3 load ≈ 40 mA typical (STM32 ~20, INA228 ~1, ISO ~3, pull-ups/LEDs ~15) + 1 mA bleeder; design 150 mA → 12 V input ≈ 45 mA (85 %). 3V3_A: ferrite 600 Ω@100 MHz + 4.7 µF + 100 nF. **Ripple on 3V3 and 3V3_A is measured at first-article bring-up, not computed.**

## 4. Relay driver (Durakool DG57CM-5021-76-1012-R + IRLML0060TRPBF)

Relay (reported): SPST-NO, 12 V coil, ≈1.6 W, DC1 80 A@12 V / 60 A@36 V / 50 A@48 V, max switching 145 VDC, operate ≈ 7 ms [UR]. OSBAMS stays ≤ 44 V / ≤ 10 A: margin ≥ 5× at 48 V (50 A) vs 10 A. Coil 90 Ω [UR].

| Coil V | I | P |
|---|---|---|
| 10.5 V | 117 mA | 1.23 W |
| 11.6 V | 129 mA | 1.50 W |
| 12.0 V | 133 mA | 1.60 W |
| 15.0 V | 167 mA | 2.50 W |

Coil data [UR] [UR]: 90 Ω ±10 % at 23 °C → 121-148 mA at 12.0 V; must-operate ≤ 7.2 V, must-release ≥ 1.2 V (23 °C); **maximum allowable coil voltage 17.4 V at 23 °C but only 12.5 V at 85 °C** → the XDR is set to 12.0 V and must never be run at 15 V (the 15 V row above is shown only to document the exclusion). Coil node after D2 (SS14 drop ≈ 0.4 V) with a 12.0 V ± 1 % XDR ≈ 11.7 V: operate margin 7.2 V → 4.5 V, max-allowable margin 12.5 V → 0.8 V at 85 °C [UV: XDR tolerance not read].

**Q1 = IRLML0060TRPBF (60 V SOT-23 logic-level)** — RDS(on) is not specified at 3.3 V (manufacturer: ≤ 116 mΩ at 4.5 V, ≤ 92 mΩ at 10 V [UR]; typical output/transfer curves include 2.8-3.5 V but were not available to this build); using a pessimistic placeholder 0.5 Ω [UV]: VDS = 85 mV and P = 14.5 mW at 170 mA. Gate overdrive at 3.3 V × 0.97 with VGS(th) max 2.5 V [UR] is 0.7 V — adequate for a 0.17 A load but **Infineon's typical curves at VGS 3.0/3.3 V make the load plausible, but RDS(on) is not guaranteed at 3.3 V → first-article VDS / coil-current measurement is the validation item**. VDSS 60 V [UR] vs the 24.4 V TVS clamp → margin 35.6 V. Alternates: Diodes DMN6140L-7 (60 V), AOS AO3400A (30 V, 2.5 V-specified).
**Margin estimate at VGS = 3.2 V (3.3 V × 0.97), worst-case VGS(th) 2.5 V and the 4.5 V RDS(on) max 116 mΩ [UR]:** transconductance parameter k ≈ 1/(RDS(on)·(4.5 − VGS(th))) = 4.3 A/V² → RDS(on) ≈ 331 mΩ (the 0.5 Ω placeholder is 1.5× that), saturation current ≈ ½k(VGS − VGS(th))² = **1.1 A = 7× the 0.15 A coil load** (square-law extrapolation near threshold = estimate [UV], not a guarantee). **Classification: keep IRLML0060 — comfortably inside the transfer-characteristic region by this estimate; RDS(on) at 3.3 V is not guaranteed, so the first-article measurements are mandatory (VGS, VDS while energized, coil current, MOSFET temperature) — a first-article item, not a PCBWay blocker.**

Gate network: 220 Ω in series, 10 kΩ pull-down → default OFF in reset/unpowered/Hi-Z. Flyback: S1M-13-F (1 A 1000 V), cathode on COIL_V; **no fast-release TVS in RC1** (a 27 V TVS would put 12+27 V on the MOSFET).
Flyback energy ½LI² = 1.78 mJ (L = 0.2 H [UV]); diode-only decay τ = L/R = 2.2 ms (release time to be taken from the relay datasheet).

## 5. VO610A-1 stages (status inputs, active-low)

**Guaranteed data (user-relayed [UR]):** CTR min 13 % / typ 30 % at IF = 1 mA, VCE = 5 V; CTR min 40 % / max 80 % at IF = 10 mA. **The arbitrary 20 % CTR has been deleted.** VF max 1.6 V is the manufacturer's value at IF = 50 mA, used as a conservative bound at the low IF here; VCE(sat) max 0.3 V (IF = 10 mA, IC = 1 mA) [UR] — the design keeps the more conservative 0.4 V at 0.07 mA. The 0.8 temperature and 0.8 aging factors are **DESIGN_MARGIN** (project assumptions, not manufacturer data).

Method (design-to-guaranteed):
1. CTR_eff = CTR_min(1 mA) × temp derate × aging derate = 0.13 × 0.80 [UV] × 0.80 [UV] = **0.0832**; valid for every IF ≥ 1 mA by the monotonic-curve assumption [UV] (CTR rises from 1 mA to 10 mA).
2. Pull-up demand I_pu = (3.3 V − VCE(sat) 0.4 V [UV]) / R_pu. Require IF × CTR_eff ≥ 2 × I_pu (saturation margin 2).
3. IF = (Vsupply − VF_max 1.6 V [UR]) / R_led (R_led +1 % tolerance); evaluate at the minimum supply.

R_pu = 47 kΩ → I_pu = 61.7 µA → IF_min = 2 I_pu / CTR_eff = **1.48 mA**.

**ESTOP_SENSE: R24 5.6 kΩ (0603)** — R_led 5.6 kΩ, R_pu 47 kΩ, minimum supply 10.5 V

| V | IF | IC available | margin | R dissipation (total) |
|---|---|---|---|---|
| 10.5 V | 1.57 mA | 131 µA | ×2.12 | 14 mW |
| 11.6 V | 1.77 mA | 147 µA | ×2.38 | 18 mW |
| 12.0 V | 1.84 mA | 153 µA | ×2.48 | 19 mW |
| 15.0 V | 2.37 mA | 197 µA | ×3.19 | 31 mW |

Voltage for 2× margin: **10.0 V** ≤ 10.5 V → **PASS**.

**RELAY_FB: R26+R27+R28 = 3 × 4.7 kΩ = 14.1 kΩ (1206)** — R_led 14.1 kΩ, R_pu 47 kΩ, minimum supply 24 V

| V | IF | IC available | margin | R dissipation (total) |
|---|---|---|---|---|
| 24 V | 1.57 mA | 131 µA | ×2.12 | 35 mW |
| 28 V | 1.85 mA | 154 µA | ×2.50 | 48 mW |
| 30 V | 1.99 mA | 166 µA | ×2.69 | 56 mW |
| 36 V | 2.42 mA | 201 µA | ×3.26 | 82 mW |
| 42 V | 2.84 mA | 236 µA | ×3.83 | 113 mW |
| 44 V | 2.98 mA | 248 µA | ×4.01 | 125 mW |
| 48 V | 3.26 mA | 271 µA | ×4.39 | 150 mW |
| 77.4 V | 5.32 mA | 443 µA | ×7.18 | 399 mW |

Voltage for 2× margin: **22.7 V** ≤ 24 V → **PASS**.

Relay-feedback supported pack range 30–44 V is covered down to 24 V (20 % below the 30 V minimum, allowing pack sag under load). At the 77.4 V TVS level (10/1000 µs rating) each 4.7 kΩ resistor dissipates 136 mW and at the 100.6 V (8/20 µs) level 232 mW (1206 = 250 mW; short transients only). At 44 V: 43 mW each. The 1N4148 across each LED limits reverse voltage to ≈ 0.7 V (LED VR max 6.0 V [UR]). Relay open: the load side floats at ≈ 0 V → LED dark → PC9 HIGH (fail-safe: 'not closed'); E-stop open or wire broken → no current → PA0 HIGH (fault).

## 6. ARM_SENSE divider (status only)

`COIL_V → 270 k → ARM_DIV → 100 k → GND; ARM_DIV → 1 k → ARM_SENSE (PC10) + 100 nF; BAT54S clamp D13 (GND / +3V3)`

| COIL_V | ARM_DIV |
|---|---|
| 0 V | 0.00 V |
| 10.5 V | 2.84 V |
| 11.6 V | 3.14 V |
| 12.0 V | 3.24 V |
| 15.0 V | 4.05 V |

VIH 2.31 V [UV] → valid HIGH from 10.5 V (2.84 V); at 15 V the node is 4.05 V, held to ≈ 3.6 V by D13's upper diode. Source impedance 73 kΩ → clamp back-feed ≤ (15 − 0.3)/270 kΩ = 54 µA, and ARM_SENSE sits on the +12V chain, which always powers the buck first. HIGH = ARM closed with E-stop closed; E-stop open → COIL_V = 0 → ARM unknown. Sensing only: no firmware path can energize K1.

## 7. I²C buses (tr = 0.8473·R·C)

| Bus | R | Cb | tr | limit |
|---|---|---|---|---|
| I2C1 INA228 (board only, ~125 kHz in firmware) | 4.7 k | 50 pF | 199 ns | 1000 ns (standard) |
| I2C1 at 400 kHz | 4.7 k | 50 pF | 199 ns | 300 ns |
| I2C2 TC74, 1 m cable | 4.7 k | 155 pF | 617 ns | 1000 ns |
| I2C2 TC74, 1.5 m (limit) | 4.7 k | 215 pF | 856 ns | 1000 ns |
| I2C2 TC74, 2 m (2.2 k alt.) | 2.2 k | 285 pF | 531 ns | 1000 ns |

TC74 on its own I²C2 (PB10/PB11) ≤ 100 kHz, cable ≤ 1.5 m; beyond that stop and propose another interface (DS18B20/NTC are contingency only).
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

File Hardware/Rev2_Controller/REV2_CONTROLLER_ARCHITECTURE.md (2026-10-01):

# OSBAMS Rev.2 Controller — architecture (rev D, matches RELEASE CANDIDATE 1)

**Status: RC1 is a complete design package for REVIEW. It is NOT authorization to fabricate.** The schematic, PCB layout and outputs live in `OSBAMS_Rev2_RELEASE_CANDIDATE_1/`; fabrication remains gated by manufacturer-document verification (`DATASHEET_VERIFICATION.md`). Rev.1 is reference only (`legacy/reference/rev1_kicad/`).

Evidence states used everywhere: **VERIFIED_LOCAL** (read by the build) · **USER_RELAYED_MANUFACTURER** (manufacturer data supplied by the user; PDF not opened by the build; tag [UR]) · **UNVERIFIED** (assumption/proposal; tag [UV]).
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

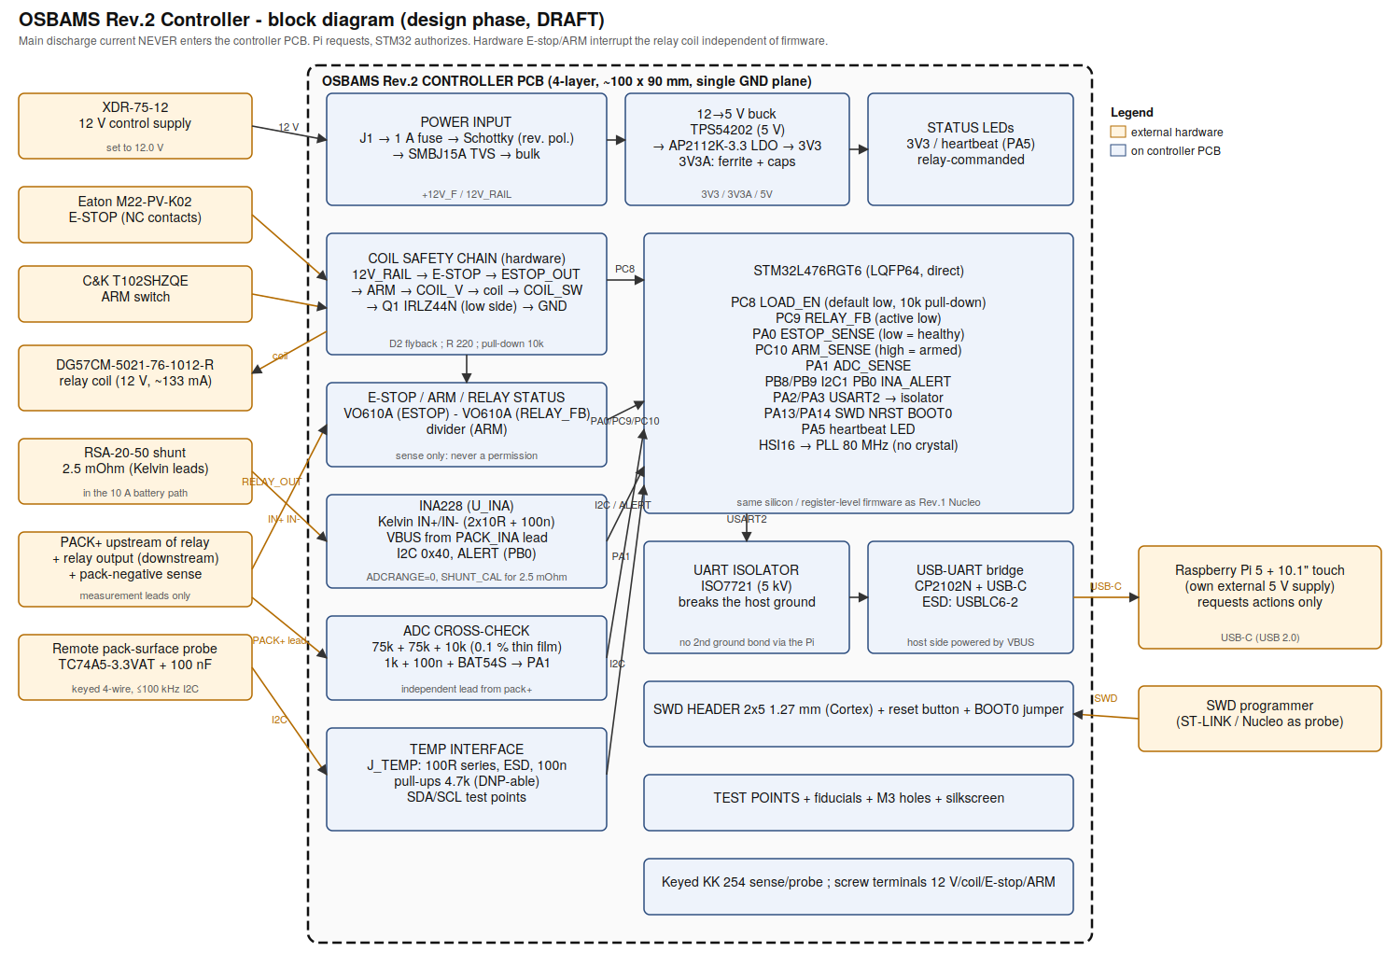
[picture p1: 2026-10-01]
Hardware/Rev2_Controller/reference/chat_draft/REV2_BLOCK_DIAGRAM_chat.png

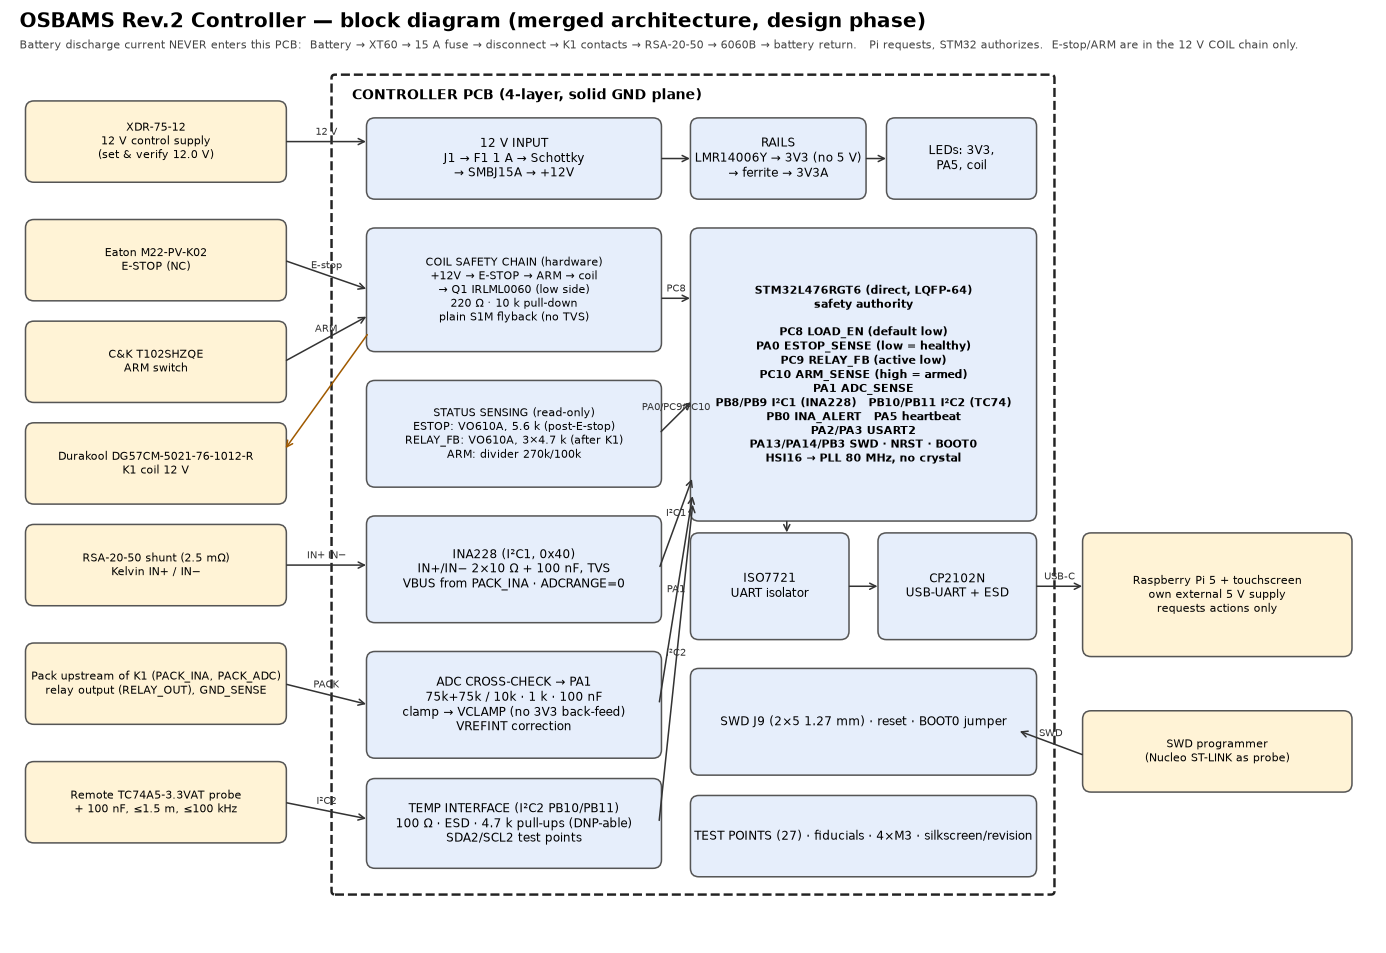
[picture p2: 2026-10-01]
Hardware/Rev2_Controller/REV2_BLOCK_DIAGRAM.png

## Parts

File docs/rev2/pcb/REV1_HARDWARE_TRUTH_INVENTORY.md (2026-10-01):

# OSBAMS Rev.1 Hardware Truth Inventory

**Purpose:** reconcile what Rev.1 actually is (KiCad + Mouser invoices + firmware) before any Rev.2 manufacturing files are made.
**Date:** 2026-09-30 · **Scope:** inventory only. No redesign, no Gerbers/BOM/CPL.
**Rule applied:** KiCad + invoices + firmware are evidence. Old planning documents lose any conflict.

## 0. Method, evidence keys, vocabulary

**Evidence keys**

| Key | Source |
|---|---|
| SCH / PCB | `OSBAMS_PCB.kicad_sch` / `.kicad_pcb` (byte-identical to `Hardware/Schematic/OSBAMS PCB.*` in the repo) |
| INV-A | Mouser 91393224, 2026-07-14 |
| INV-B | Mouser 91665418, 2026-07-29 |
| INV-C | Mouser 91854909, 2026-08-07 |
| INV-D | Mouser 91939009, 2026-08-13 |
| FW | `Firmware/` (version string `0.9.0-dev3`) |
| CT / HD / VR | `CONNECTION_TABLE.md` / `Documentation/HARDWARE_DESIGN.md` / `Documentation/VALIDATION_REPORT.md` |
| BOMX / PL | `Hardware/OSBAMS_BOM.xlsx` / `Hardware/OSBAMS_Final_Design_Purchase_List.xlsx` |
| FUND / RPT | Rev.2 funding request (2026-09-24) / ENGR696 report |

**Status:** CONFIRMED = at least two independent sources agree and none conflicts · ASSUMED = one source only, or inferred · MISSING = required/used but absent from KiCad and/or evidence · CONFLICT = sources disagree.
**Rev.2 recommendation:** KEEP · FIX · REPLACE · REMOVE · VERIFY_PHYSICALLY.

**Validation vocabulary.** The repo's own terms are PASS / PARTIAL / NOT RUN (VR §3) and "Host-tested" (VR §2, citing `MODULE_STATUS.md`, which is **not in the repo**). `HARDWARE_VALIDATED` is not defined anywhere in the repo, and nothing here is assigned it. Claims that Rev.1 "worked" come from FUND/RPT (operator-reported); **no recorded bench data exists in the repo**. VR is dated 2026-07-22, predates the build, and lists every hardware ACC row NOT RUN. It is stale, not contradicted.

**"Installed?"** column: Mouser invoices prove purchase, not installation. "Unknown" means nothing in the repo records what was soldered or wired.

## 1. Headline finding: what the KiCad project actually is

The KiCad project is **not** the whole Rev.1 system. It is an 80 × 80 mm, 2-layer carrier with **16 schematic symbols** (plus 4 board-only M3 holes):

- 12 V control input with reverse-polarity diode and TVS (J1, D3, D1, C1)
- E-stop loop terminals (J3) and contactor-coil MOSFET driver (J2, Q1, R1, R2, D2)
- I²C sensor bus: INA228 module header (J4), TC74 (U1), bypass caps (C2, C3)
- Nucleo interface header (J5) and UART header (J6)

**Not in KiCad at all:** STM32 (it is a plug-in Nucleo-L476RG via J5), INA228 silicon (Adafruit module via J4), relay/contactor, shunt, fuses, E-stop switch, ARM switch, VO610A feedback optocoupler, ADC divider, 1N4148, pack-side TVS, XT60, any 5 V rail, test points. Several of these are in firmware and on invoices. The Rev.1 power stage, feedback and ADC circuits were **hand-wired off-board and are undocumented in KiCad.**

J5 carries only: 3V3, GND, SDA(PB9), SCL(PB8), GPIO_GATE(PC8), UART TX/RX(PA2/PA3), SPARE. **PA0 (E-stop sense), PC9 (K1 feedback) and PA1 (ADC divider) are not on J5.**

## 2. Critical conflicts found (details in the tables)

1. **Diode polarity: symbol vs footprint (D1, D2, D3).** Custom symbols `OSBAMS:D_H` and `OSBAMS:D_TVS` have **pin 1 = anode**. KiCad's `D_DO-201AD` and `D_SMB` footprints have **pad 1 = cathode** (PCB shows `K` text and the silkscreen band at pad 1). The PCB nets are therefore reversed relative to schematic intent:
   - D3 (series reverse-protect): cathode on `12V_IN`, anode on `+12V`. Blocks normal polarity.
   - D2 (coil flyback): cathode on `COIL_SW` (drain), anode on `COIL_V` (+12 V). Conducts when Q1 turns on, which would short +12 V through the diode to Q1.
   - D1 (SMBJ15A): cathode on GND, anode on `+12V`. Forward-biased clamp across the 12 V rail.
   A PCBA built from these files would be dead or damaged. Since Rev.1 reportedly worked, the diodes were **probably soldered against the footprint marking**. That must be confirmed on the physical board.
2. **Temperature subsystem**: root cause not determinable from the repo (§5). Variant/address/voltage are consistent for TC74A5-3.3VAT; several other defects exist.
3. **Relay identity**: firmware says Durakool `DG57CM-5021-76-1012-R`; BOMX says Albright SW60; FUND says Durakool "80A" in Rev.1 and SW60 planned for Rev.2. No invoice exists for either.
4. **Netclass not applied**: the project defines `Powerpath(12V/coil)` = 1.2 mm and `3V3` = 0.5 mm, but patterns `+12V, COIL_SW, COIL_V` do not match the actual net names (`/+12V`, `/COIL_SW`, …). Every routed track is **0.3 mm**, including the coil/12 V path.
5. **Purchased vs footprint**: C2/C3 (0805 purchased, 5 mm disc footprint); terminal blocks (Adam Tech EB21A-02-C pluggable purchased, MaiXu MX126 fixed footprint); headers (Samtec 2×2 RA and GCT 14-pos purchased, 1×4 and 2×4 footprints).
6. **Firmware current limits exceed hardware**: `OSBAMS_DEFAULT_MAX_CURRENT_MA = 18500` vs 15 A fuse, 20 A shunt and the 10 A Rev.2 ceiling.
7. **BOMX is stale throughout**: designators collide with the schematic (R1/R2 = I²C pull-ups in BOMX but gate/pull-down in SCH; D1 flyback vs TVS; U1 Nucleo vs TC74); TC74 listed as `A0-5.0VAT`; flyback 1N4007 vs 1N5408; E-stop Schneider vs Eaton.

## 3. Component and circuit inventory

Columns: Ref · Function · Mfr / exact MPN · SCH value · PCB footprint · Purchase evidence · Firmware dependency · Installed? · Status · Rev.2.

### 3.1 On the KiCad board

| Ref | Function | Mfr / MPN | SCH value | PCB footprint | Purchase evidence | Firmware dep. | Installed? | Status | Rev.2 |
|---|---|---|---|---|---|---|---|---|---|
| U1 | Pack temperature sensor, I²C | Microchip **TC74A5-3.3VAT** | `TC74A5-3.3VAT` | `TO-220-5_Vertical` | INV-C L1, qty 2, $1.82 | `TC74_I2C_ADDR = 0x4D<<1`; mandatory channel `SENSOR_CH_TEMP_PACK`; `TC74_Init` | **Unknown** (variant physically fitted not recorded) | **CONFLICT** (SCH, FW, INV-C, RPT agree on A5-3.3V; BOMX says `TC74A0-5.0VAT`; a different part, TC74A1-5.0VCTTR, was also bought) | **FIX** + VERIFY_PHYSICALLY (§5) |
| C2 | TC74 bypass | Vishay **VJ0805Y104JXXAT** (0.1 µF 25 V 0805) if purchased part used | `0.1uF (TC74 bypass)` | `C_Disc_D5.0mm_W2.5mm_P5.00mm` (THT) | INV-D L2, qty 2 (0805 SMD) | none | Unknown | **CONFLICT** (SMD bought, THT footprint). C2 sits ~16.7 mm from U1 VDD | **FIX** (footprint ↔ part; place at VDD pin) |
| C3 | Logic 3V3 bypass | as C2 | `0.1uF (logic bypass)` | same THT disc | as C2 | none | Unknown | **CONFLICT** | **FIX** |
| J4 | INA228 module header (3V3, GND, SCL, SDA) | Adafruit **5832** INA228 module | `INA228_MODULE` | `PinHeader_1x04_P2.54mm` | INV-B L6, $14.95 | `ina228.c` addr `0x40`; `SHUNT=2500 µΩ`, `IMAX=30000 mA`; mandatory V/I/P channels | FUND: module "soldered directly to the Rev.1 board" (operator-reported) | **CONFIRMED** (module identity, bus wiring, FW comms operator-reported). Module IN+/IN−/VBUS wiring and onboard-shunt handling are **not in KiCad** | **KEEP**; VERIFY_PHYSICALLY pin order, ALERT/A0/A1 straps, onboard shunt state |
| U1/J5 | Nucleo interface (3V3, GND, SDA, SCL, GPIO_GATE, TX, RX, SPARE) | n/a | `NUCLEO_INTERFACE` | `PinHeader_2x04_P2.54mm` | none that matches (see §3.2) | PB8/PB9, PC8, PA2/PA3 | Unknown | **ASSUMED** (SCH note: "keyed connector"; footprint is a plain unkeyed header; which Nucleo pins J5 reaches is undocumented) | **VERIFY_PHYSICALLY**; add keying |
| J6 | UART header (3V3, GND, TX, RX) for host | n/a | `UART_HDR` | `FanPinHeader_1x04_P2.54mm` | none | USART2 115200 (`system_clock.h`) | Unknown | **ASSUMED**. Net names are Nucleo-side (TX = Nucleo TX); pin 1 exposes 3V3, a contention risk if tied to a Pi 3V3 pin; PA2/PA3 are also on the ST-LINK VCP | **FIX** labels, drop 3V3 pin |
| Q1 | Contactor-coil low-side driver | Infineon **IRLZ44NPBF** | `IRLZ44NPBF` | `TO-220-3_Vertical` (G-D-S) | INV-B L8, qty 2, $1.80 | PC8 `LOAD_ENABLE`, active-high, default low (`load_driver.c`) | Unknown, probably yes | **CONFIRMED** (SCH + INV + FW + footprint pin map) | **KEEP** |
| R1 | Gate resistor | Not purchased from Mouser (no resistor on any invoice) | `220 (gate)` | `R_Axial_DIN0207…P10.16mm` | none | none | Unknown | **CONFLICT** (BOMX/PL say 100 Ω) | VERIFY_PHYSICALLY; KEEP |
| R2 | Gate pull-down | not on invoices | `10k (gate pulldown)` | same | none | FW header relies on a pull-down so reset ⇒ load OFF | Unknown | **ASSUMED** | VERIFY_PHYSICALLY; KEEP |
| D2 | Coil flyback | onsemi **1N5408G** | `1N5408 (flyback)` | `D_DO-201AD_P15.24mm` | INV-B L9, qty 2 | none (safety-relevant) | Unknown | **CONFLICT**: polarity (§2.1); BOMX says 1N4007 | **FIX**; VERIFY_PHYSICALLY band orientation |
| D3 | Reverse-polarity, series on 12 V | Vishay **SB560-E3/73** | `SB560-E3/73 (rev-polarity, Schottky)` | `D_DO-201AD_P15.24mm` | INV-C L2, qty 2 | none | Unknown | **CONFLICT**: polarity (§2.1) | **FIX** |
| D1 | 12 V rail TVS | Littelfuse **SMBJ15A** | `SMBJ15A (confirmed, DO-214AA/SMB)` | `D_SMB` | INV-C L7, qty 2 | none | Unknown | **CONFLICT**: polarity (§2.1) | **FIX** |
| C1 | 12 V bulk | Panasonic **ECA-1EM100I** (10 µF 25 V) | `ECA-1EM100I: 10uF 25V` | `CP_Radial_D5.0mm_P2.00mm` | INV-B L10, qty 5 | none | Unknown | **CONFIRMED** | **KEEP** |
| J1 | 12 V input (+12V_IN, GND) | See §3.2 terminal blocks | `PWR_IN_12V` | MaiXu `MX126-5.0-02P` | none matches | none | Unknown | **CONFLICT** | **VERIFY_PHYSICALLY** |
| J2 | Contactor coil (COIL_V, COIL_SW) | as J1 | `CONTACTOR_COIL` | MX126 | as J1 | PC8 via Q1 | Unknown | **CONFLICT** | VERIFY_PHYSICALLY |
| J3 | E-stop loop (+12V → COIL_V) | as J1 | `ESTOP_LOOP` | MX126 | as J1 | none (sense is separate, §3.3) | Unknown | **CONFLICT** | VERIFY_PHYSICALLY |
| MH1–4 | M3 mounting | DFRobot FIT0066 (nylon M3×10, hardware) | PCB-only | `MountingHole_3.2mm_M3` | INV-C L3 | none | Unknown | **ASSUMED** | KEEP; match enclosure |

SCH `U1` TC74 row above uses the schematic's U1 designator. BOMX uses U1 for the Nucleo and U3 for the TC74: another designator collision.

### 3.2 Purchased, but no matching KiCad part

| Item | Mfr / MPN | Invoice | What the repo says | Status |
|---|---|---|---|---|
| Terminal blocks | Adam Tech **EB21A-02-C**, 2P pluggable, ×5 | INV-C L6 | KiCad uses fixed MaiXu MX126-5.0 footprint; pitch of EB21A must be checked against 5.00 mm | **CONFLICT** → VERIFY_PHYSICALLY |
| Header | Samtec **TSW-102-08-H-D-RA** (2×2 right-angle) ×1 | INV-C L5 | matches no KiCad footprint (J4 is 1×4, J5 is 2×4) | **MISSING** link |
| Header/socket | GCT **BG040-14-A-0450-0300-N-G** (14-pos 2.54 mm) ×2 | INV-C L4 | matches no KiCad footprint | **MISSING** link |
| INA260 module | Adafruit **4226** | INV-A L3 | superseded: INA260 36 V limit (CT) | **REMOVE** from Rev.2 scope |
| Fuses 5 A / 10 A | Littelfuse **0997005.WXN**, **0997010.WXN**, ×5 each | INV-A L1–2 | not the selected fuse (15 A); a 10 A fuse nuisance-trips at the 10 A ceiling | **REMOVE** from Rev.2 BOM |

### 3.3 Circuits and parts that exist only off-board, or only in firmware/purchase records

| Item | Function | Mfr / MPN | SCH value | Footprint | Purchase evidence | Firmware dep. | Installed? | Status | Rev.2 |
|---|---|---|---|---|---|---|---|---|---|
| STM32L476RG controller | Safety authority, acquisition | ST **NUCLEO-L476RG** (module, not on PCB) | via J5 | n/a | BOMX "Owned"; FUND spare Nucleo (not Mouser) | whole firmware; register-level, PCLK1 40 MHz | Yes (FW builds/flashes; INA228 comms and UART telemetry operator-reported, RPT/FUND) | **CONFIRMED** (as module) | **KEEP** module (PCBWay cannot place a Nucleo) |
| INA228 (voltage/current) | Primary metrology | TI INA228 on Adafruit 5832 | see J4 | | INV-B L6 | addr `0x40`, `ADCRANGE=0`, `SHUNT_CAL` fixed (header comments) | per FUND "working" | **CONFIRMED** (module) | **KEEP** |
| Independent ADC voltage | Redundant V cross-check | Resistors: **no MPN anywhere** | none | none | none; PL says `ADC-R` "DO NOT ORDER YET" | `adc_safety.c`: PA1/ADC1_IN6, ratio 16:1 (150 kΩ/10 kΩ, comment says "confirmed"), 1.5 V agreement window; missing ADC ⇒ SENSOR_DISAGREE fault | Unknown | **CONFLICT** (FW "confirmed physical divider" vs PL "unfinished" vs not in KiCad). No clamp or RC filter is documented | **VERIFY_PHYSICALLY**, then **FIX** (add to PCB with protection) |
| Shunt | Current sense | Bourns **RSA-20-50** (20 A / 50 mV = 2.5 mΩ) | none | chassis mount | INV-B L1, $39.46 | `OSBAMS_SHUNT_MICRO_OHM = 2500` | RPT: shunt wiring in place (unspecific) | **CONFIRMED** (purchase = FW value). Module/shunt Kelvin wiring is undocumented | **KEEP**; fix FW range config |
| Main fuse | Pack-path protection | Littelfuse **0997015.WXN** (58 V, 15 A) | none | inline | INV-B L4, qty 2 | none | Unknown | **CONFIRMED** purchased | **KEEP** |
| Fuse holder | | Littelfuse **0FHM0001ZXJ-RED** (MINI inline) | none | inline | INV-B L3, qty 1 | none | Unknown | **ASSUMED** (holder DC voltage/current rating not in repo; must cover 42 V / 15 A) | **VERIFY_PHYSICALLY**, datasheet check |
| Relay/contactor K1 | Pack disconnect | Rev.1: Durakool **DG57CM-5021-76-1012-R** (string only in `load_driver.c`), 12 V coil, "80 A" (FUND, RPT); no aux contact (FW comment) | none | off-board; coil via J2 | **None** (not on any Mouser invoice; RPT lists $18) | PC8 command; K1 state read via PC9 | Unknown, "automotive relay substituted" (FUND) | **ASSUMED** (exact variant from a code comment only). BOMX/PL say Albright **SW60** (never bought) | **REPLACE** (SW60 + aux per FUND, not yet quoted); VERIFY_PHYSICALLY label of installed relay |
| Relay MOSFET driver | see Q1/R1/R2/D2 | | | | | | | CONFIRMED part, polarity CONFLICT | KEEP/FIX |
| Feedback optocoupler | K1 closed ⇒ HV present ⇒ PC9 LOW | Vishay **VO610A-1** | none | none | INV-D L1, qty 2 | `load_driver.c`: PC9 active-low, pull-up "external", `LOAD_CLOSE_TIMEOUT_MS=250`, `Load_Disable` returns LOAD_STUCK if still "closed" | Unknown (FW states it is wired) | **MISSING** from KiCad: resistor chain values, pull-up, 1N4148 role, pack-side wiring all undocumented | **VERIFY_PHYSICALLY**, then **FIX** (draw it); REPLACE logic if SW60 aux is used |
| 1N4148 | Not referenced anywhere | onsemi **1N4148** ×2 | none | none | INV-D L3 | none | Unknown | **MISSING** (purpose undocumented; do not assume) | VERIFY_PHYSICALLY |
| Pack-side TVS | HV bus transient clamp | Bourns **1.5SMBJ48A** ×2 | none (SCH note: "belongs on HV battery bus ONLY") | none | INV-B L2 | none | Unknown | **ASSUMED** purchased for the pack bus; not on the PCB; PL says `TVS1` "DO NOT ORDER YET" (stale) | VERIFY_PHYSICALLY; define location |
| E-stop | Hardware coil interrupt | Eaton **M22-PV-K02** | `ESTOP_LOOP` (J3 only) | panel | INV-B L11, $58.61 | PA0 `ESTOP_SENSE`: LOW healthy, HIGH tripped, **no internal pull**, external pull-up assumed (`estop.c`) | FUND: E-stop is in the enclosure | **CONFIRMED** (switch, loop); **MISSING** sense/pull-up circuit; BOMX "Schneider XB4BS8445" stale | **KEEP** loop; **FIX** add sense circuit; VERIFY_PHYSICALLY contact block (NC count/rating) |
| ARM toggle | Control enable | C&K **T102SHZQE** (SPDT, invoice text "Off-None-On") | none | panel | INV-B L12 | **no firmware reference** | Unknown | **MISSING** from KiCad; where it sits in the circuit is not recorded | VERIFY_PHYSICALLY; add to schematic |
| 12 V supply | Control power | Mean Well **XDR-75-12** (74.88 W, 6.24 A) | none | DIN | INV-B L5, $36.50 | none | Unknown, referenced as installed in FUND | **CONFIRMED** purchased | **KEEP** |
| 5 V rail (Nucleo / Pi) | | RPT: "Pololu 5 V" (no MPN), FUND: 12→5 V converter for Pi 5 + touchscreen + STM32 | none; **no 5 V net on the PCB** | none | none on Mouser | none | Unknown | **MISSING** (no MPN, no capacity; no listed part is sized for Pi 5 + 10.1" display + STM32) | **FIX**; BLOCKER |
| Raspberry Pi interface | UI host | Pi 5 + 10.1" display | none | none | none | protocol over USART2 (ST-LINK VCP via USB per CT; J6 is an unlabelled alternative) | n/a | **ASSUMED**; no Rev.1 hardware defines the Pi link | FIX / decide |
| UART/USB | Host link | Nucleo ST-LINK VCP, USB micro (CT) | J5/J6 | | n/a | 115200 | Yes (telemetry operator-reported) | **CONFIRMED** (CT + FW + RPT) | KEEP |
| Programming/debug | | Nucleo on-board ST-LINK | none | none | n/a | | Yes | **CONFIRMED** (as module). No SWD header on PCB | **KEEP**; add header only if MCU moves on-board |
| Battery connector | Pack interface | Amass **XT60** (BOMX planned) | none | none | **none** | none | Unknown | **MISSING** purchase evidence | **KEEP** XT60 only (no XT90) |
| Test points | | | none | none | none | | n/a | **MISSING** (none exist) | add (§ Change Request) |

## 4. Power architecture review (Rev.2 target: 30–42 V packs, XT60, Agilent 6060B, 300 W, 10 A)

| Topic | Finding | Status |
|---|---|---|
| Voltage margin | INA228 VBUS ≤ 85 V; fuse 58 VDC; SB560 60 V; IRLZ44N 55 V (12 V domain only); 1.5SMBJ48A V<sub>RWM</sub> 48 V: all clear 42 V. SMBJ15A V<sub>RWM</sub> 15 V on a 12 V rail | CONFIRMED by part rating (datasheets not in repo; ratings quoted from invoice descriptions) |
| Power vs current ceiling | 300 W load ceiling means the usable current is P/V: **10 A at 30 V, ≈7.1 A at 42 V**. The 10 A ceiling is therefore binding only at the low end of the pack range. Firmware has **no power limit** (`DEFAULT_MAX_CURRENT_MA` 18.5 A; grep finds no 300 W limit) | CONFLICT (FW vs product spec) |
| Current chain | Fuse 15 A < shunt 20 A; firmware default 18.5 A > fuse; `INA228_IMAX_MA=30000` > shunt rating (affects only LSB size). INA228 `ADCRANGE=0` (±163.84 mV): 10 A = 25 mV on 2.5 mΩ, usable; ADCRANGE=1 would give 4× finer resolution if desired | CONFLICT (FW) |
| Contactor DC rating | No contactor datasheet in the repo. DC breaking rating at 42 V / 10 A inductive is **unverified for both** the Rev.1 relay and the planned SW60 | MISSING; BLOCKER |
| Coil supply path | Coil is fed through D3 (≈0.4–0.6 V Schottky drop) and the E-stop contacts. Coil current is **unknown** (no datasheet). Tracks are 0.3 mm | MISSING |
| Logic power | PCB takes 3V3 *from* the Nucleo (SCH note). Nothing on the PCB powers the Nucleo. FUND says Nucleo + Pi + display run from XDR-75-12 through a converter that is not specified | MISSING; BLOCKER |
| XDR-75-12 headroom | 74.88 W total; coil + Pi 5 (up to 5 V / 5 A class) + touchscreen + STM32 is plausible but unsized | ASSUMED |
| Grounding | CT says the pack's energy "never reaches the logic rails", yet the INA228 sense lines and the ADC divider (150 kΩ to pack +, 10 kΩ to GND) tie pack and logic references together. The bond point and where the divider's low side returns are undocumented | MISSING |
| Interfaces | One external load only (Agilent 6060B); desktop `electronic_load.py` has `Agilent6060BLoad` as an unimplemented stub, and an `OwonLoad` class still ships. Rev.2 hardware needs no load interface, but firmware/desktop still carry an OWON driver (out of PCB scope, flagged) | FLAG |
| Scope hygiene | No XT90 or MV/HV hardware in KiCad or firmware. `chemistry_profiles.py` still mentions NiMH (desktop, out of PCB scope) | FLAG |

## 5. Temperature subsystem: why was it offline?

**Symptom evidence.** FUND (2026-09-24): "TC74 temperature sensor is currently non-functional (offline fault)". RPT: "TC74 bring-up" still open. Firmware: `SENSOR_HEALTH_OFFLINE` on TC74 blocks `RunSelfChecks` (main.c), so the unit cannot reach IDLE. **The repo contains no bus scan, no status code, no scope capture and no photo.** `SensorManager_Init` collapses the TC74 init result to a boolean, so the failure cause (NACK vs TIMEOUT vs NOT_READY) was **not recorded**.

**Is variant/address/voltage/interface mismatch the cause?**

| Check | Result |
|---|---|
| Schematic part | TC74A5-3.3VAT, TO-220-5 |
| Firmware address | 0x4D. Matches the TC74A5 default (`1001 101b`, from Microchip DS21462 via search excerpts) |
| Purchased 3.3 V part | TC74A5-3.3VAT ×2, INV-C (2026-08-07). Consistent with SCH/FW |
| Purchased 5.0 V part | TC74A1-5.0VCTTR ×2, INV-B (2026-07-29): **A1 ⇒ address 0x49, SOT-23-5 SMD**. It cannot be dropped onto the TO-220-5 footprint |
| Rail | 3V3 from Nucleo. The datasheet states all variants operate 2.7–5.5 V; accuracy is only specified at nominal V<sub>DD</sub>. FW comment "5.0 V part would be a rail mismatch" is overstated |
| Pin map | SCH/PCB: 1 NC, 2 SDA, 3 GND, 4 SCLK, 5 VDD. Search excerpts for the TO-220 pin table were garbled; **verify against DS21462 in hand** |
| Shared bus | INA228 (0x40) reportedly works on the same SDA/SCL. So bus wiring, Nucleo pin map, pull-ups and the I²C driver are demonstrated for INA228; the fault is **TC74-specific** |
| Pull-ups | None on the PCB (R1/R2 were repurposed as gate parts; BOMX pull-ups never drawn). Pull-ups presumably come from the Adafruit module (unverified). INA228 working makes absence unlikely to be the cause |

**Therefore:** a variant mismatch can explain the failure **only if the wrong physical part (A1/5.0 V, or a different address variant) was fitted**; nothing in the repo shows which part is on the board. If TC74A5-3.3VAT is on the board correctly, address, voltage and interface all match.

**Defects found that could cause or contribute (ranked by what the evidence supports):**

1. **SCL timing outside TC74 spec.** `I2C1_TIMINGR` (PRESC=7, SCLL=19, SCLH=15 at PCLK1 = 40 MHz) gives t<sub>LOW</sub> ≈ 4.0 µs, t<sub>HIGH</sub> ≈ 3.2 µs, ≈ 125–139 kHz. The TC74 is specified 10–100 kHz with t<sub>LOW</sub> ≥ 4.7 µs and t<sub>HIGH</sub> ≥ 4.0 µs. INA228 tolerates this; the TC74 is out of spec. The header comment "~96 kHz" does not match the arithmetic. (Datasheet figures from search excerpts; verify.)
2. **Init window shorter than worst-case first conversion.** `TC74_Init` polls DATA_RDY 500× back-to-back (~0.27 ms each ≈ 135 ms) while the datasheet allows up to **250 ms** after power-on. Init at boot can return NOT_READY. Later retries (`SensorManager_AttemptRecovery`) should recover, so this alone would not give a permanent offline state.
3. **Wrong or misplaced physical part** (see above): unknown.
4. **Assembly/pin-to-pad issues**: 1.7 mm lead pitch, 0.425 mm pad gap (bridge risk when hand-soldered), lead-form vs footprint unverified; bypass cap C2 is ~17 mm from VDD.
5. **Diagnostics lost** (process gap, not a cause).

**Conclusion: the root cause is NOT established from the repository.** Four bench measurements discriminate (30 min):
1. Read the package marking on installed U1 (A-code and V-code).
2. Measure VDD at pin 5 and idle SDA/SCL levels with U1 powered.
3. Run `I2C1_Scan` and log the raw status from `TC74_Init` (NACK ⇒ address/part/solder; TIMEOUT/BUS_ERROR ⇒ bus; NOT_READY ⇒ timing).
4. Scope SCL during a TC74 transaction; compare t<sub>LOW</sub>/t<sub>HIGH</sub> with 4.7/4.0 µs.

## 6. Verification limits of this inventory

- No `kicad-cli` was available: ERC/DRC were **not run**. Connectivity was re-derived by parsing the S-expression files (schematic nets from wires/labels; PCB track connectivity per net).
- No datasheets are in the repo; ratings are from invoice descriptions, firmware comments or search excerpts and are marked for verification.
- No photos or build records exist; "Installed?" is therefore Unknown for almost everything.

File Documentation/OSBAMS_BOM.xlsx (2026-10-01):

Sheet: BOM
Reference | Description | Category | Manufacturer | Part Number | Rating | Supplier | Unit Cost (USD) | Qty | Ext Cost (USD) | Status | Installed | Verified | Approved Substitute
BT1 | Second-life 10S NMC scooter pack (device under test) | Power | various | N/A |  | recovered | $0.00 | 1 | $0.00 | N/A | No | No
J1 | Keyed power connector (XT60 or Anderson SB50) | Connector | Amass | XT60 |  | online | $3.00 | 2 | $6.00 | Planned | No | No
F1 | 58V DC fuse fast-blow (rating TBD) | Protection | Littelfuse | TBD |  | online | $4.00 | 2 | $8.00 | Planned | No | No
FH1 | Inline DC fuse holder | Protection | Blue Sea | 5504 |  | online | $12.00 | 1 | $12.00 | Planned | No | No
SW1 | Blue Sea 6006 manual battery disconnect | Protection | Blue Sea Systems | 6006 |  | online | $40.00 | 1 | $40.00 | Planned | No | No
K1 | Albright SW60 SPST contactor | Switching | Albright | SW60 |  | online | $90.00 | 1 | $90.00 | Planned | No | No
RS1 | Current sense shunt (value sized to I_max) | Sensing | Bourns | TBD |  | online | $8.00 | 1 | $8.00 | Planned | No | No
U1 | STM32L476RG Nucleo-64 development board | Control | STMicroelectronics | NUCLEO-L476RG |  | Digi-Key | $15.00 | 1 | $15.00 | Owned | No | No
U2 | INA228 current/voltage/power monitor breakout | Sensing | Adafruit | 5832 |  | Adafruit | $15.00 | 1 | $15.00 | Planned | No | No
U3 | TC74 I2C temperature sensor | Sensing | Microchip | TC74A0-5.0VAT |  | Digi-Key | $2.00 | 1 | $2.00 | Owned | No | No
R1 | I2C pullup 4.7k (SCL) | Passive | Yageo | TBD |  | online | $0.10 | 1 | $0.10 | Planned | No | No
R2 | I2C pullup 4.7k (SDA) | Passive | Yageo | TBD |  | online | $0.10 | 1 | $0.10 | Planned | No | No
Q1 | Logic-level N-MOSFET (contactor coil driver) | Control | onsemi | TBD |  | Digi-Key | $1.50 | 1 | $1.50 | Planned | No | No
D1 | Flyback diode across contactor coil | Control | onsemi | 1N4007 |  | Digi-Key | $0.20 | 1 | $0.20 | Planned | No | No
Rg1 | MOSFET gate resistor | Passive | Yageo | TBD |  | online | $0.10 | 1 | $0.10 | Planned | No | No
Rpd1 | MOSFET gate pulldown | Passive | Yageo | TBD |  | online | $0.10 | 1 | $0.10 | Planned | No | No
PS1 | 12V industrial power supply (control power) | Control Power | Mean Well | TBD |  | online | $20.00 | 1 | $20.00 | Planned | No | No
F2 | 12V control-side fuse | Protection | Littelfuse | TBD |  | online | $3.00 | 1 | $3.00 | Planned | No | No
SW2 | ARM toggle switch (control enable) | Control | NKK | TBD |  | online | $6.00 | 1 | $6.00 | Planned | No | No
ES1 | Industrial E-stop button (NC) | Safety | Schneider | XB4BS8445 |  | online | $30.00 | 1 | $30.00 | Planned | No | No
DCDC1 | 12V to 5V DC-DC converter (STM32 supply) | Control Power | Pololu | TBD |  | online | $10.00 | 1 | $10.00 | Planned | No | No
W1 | Power cable 12 AWG (pack path) | Wiring | various | N/A |  | online | $15.00 | 1 | $15.00 | Planned | No | No
W2 | Signal wire 22 AWG (sense/control) | Wiring | various | N/A |  | online | $8.00 | 1 | $8.00 | Planned | No | No
CG1 | Cable glands (enclosure entry) | Mechanical | various | N/A |  | online | $10.00 | 4 | $40.00 | Planned | No | No
RT1 | Ring terminals assortment | Connector | various | N/A |  | online | $10.00 | 1 | $10.00 | Planned | No | No
HS1 | Heat shrink assortment | Mechanical | various | N/A |  | online | $10.00 | 1 | $10.00 | Planned | No | No
ENC1 | Project enclosure | Mechanical | Hammond | TBD |  | online | $30.00 | 1 | $30.00 | Planned | No | No
 |  |  |  |  |  |  |  | Total | $380.10

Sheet: Legend
OSBAMS Bill of Materials — 0.9.0-dev1 (Engineering Prototype)
This BOM is NOT frozen. Parts are starting selections; ratings, exact part
numbers, and approved substitutes must be finalised before the hardware is frozen.
Column | Meaning
Reference | Schematic reference designator (J1, F1, K1, ...)
Rating | Voltage/current/temperature rating — TO BE FILLED with datasheet values
Status | Planned / Owned / Ordered
Installed | Yes once physically installed on the fixture
Verified | Yes once the installed part is bench-verified
Approved Substitute | A qualified alternate part — required for critical items
Critical items needing documented DC ratings before freeze:
- Contactor (K1): published DC breaking rating at 42-60 VDC under load
- Main fuse (F1): documented DC interrupt rating at working voltage
- Shunt (RS1): value finalised at calibration

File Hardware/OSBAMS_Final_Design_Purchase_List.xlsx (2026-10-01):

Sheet: Final Purchase List
Priority | Vendor | Reference | Item | Qty | Unit / Measurement | Required Rating / Specification | Suggested Part / Brand | Purchase Status | Notes
High | Other vendor | K1 | DC contactor | 1 | each | 12 V coil; published DC breaking rating for 42-60 VDC at >=10 A | Albright SW60 | Albright SW60 - A or C | Critical safety part; do not use generic relay
High | Other vendor | K1-AUX | Contactor auxiliary contact | 1 | each | Compatible with selected SW60; at least 1 NO contact | Albright compatible auxiliary | with SW60 -now skipping auxiliary ??? Quote | Used for contactor feedback
High | Other vendor | SW1 | Manual battery disconnect | 1 | each | DC battery disconnect; rating comfortably above 42 V / 10 A | Blue Sea 6006 | bass pro | Main service disconnect
High | Other vendor | F1 | Main DC fuse | 2 | each | 15 A target; >=58 VDC; documented DC interrupt rating | Littelfuse / Eaton DC fuse | HOLD - verify part | One installed plus one spare
High | Other vendor | FH1 | Covered main fuse holder | 1 | each | Matches selected DC fuse; covered touch-safe terminals | Blue Sea 5504 or exact matching holder | HOLD - match fuse | Must accept selected fuse style
High | Other vendor | RS1 | Precision current shunt | 1 | each | Final range sized for 0-10 A; Kelvin terminals; output within INA228 range | 15 A/50 mV or 20 A/50 mV candidate | HOLD - finalize value | Do not buy 50 A/75 mV unless range decision changes
High | Mouser / Digi-Key | PS1 | Industrial AC/DC power supply | 1 | each | 120 VAC input; 12 VDC output; >=2 A; enclosed or DIN-rail | Mean Well | HOLD - select exact PN | Separate control power
High | Mouser / Digi-Key | DCDC1 | 12 V to 5 V DC/DC converter | 1 | each | Regulated 5 V; >=2 A; input includes 12 V | Pololu / Murata | Buy after exact PN | Powers STM32/control electronics
High | Mouser / Digi-Key | ES1 | Emergency-stop assembly | 1 | assembly | Twist/pull release; red mushroom; industrial panel mount | Schneider XB4 series | Buy | Include operator, collar, and contact block
High | Mouser / Digi-Key | ES1-NC | E-stop normally-closed contact block | 1 | each | NC contact; >=24 VDC / 2 A | Schneider compatible NC block | Buy | Hardwired in series with contactor coil
High | Mouser / Digi-Key | SW2 | ARM maintained switch | 1 | each | Maintained SPST/SPDT; >=24 VDC / 2 A | NKK | Buy | Control enable switch
High | Mouser / Digi-Key | Q1 | Logic-level N-channel MOSFET | 2 | each | VDS >=60 V; fully enhanced at 3.3 V gate; coil-current capable | Exact PN TBD | HOLD - select exact PN | One installed, one spare
High | Mouser / Digi-Key | D1 | Coil flyback / suppression diode | 2 | each | Rated for selected coil current and transient energy | 1N4007 candidate | HOLD - verify with coil | One installed, one spare
High | Mouser / Digi-Key | F2 | 12 V control fuse | 2 | each | 1 A target; >=32 VDC | Littelfuse | Buy after PSU/coil check | One installed, one spare
High | Mouser / Digi-Key | F2-H | Control fuse holder | 1 | each | Matches F2; finger-safe preferred | Littelfuse / Eaton | Buy after fuse selection | Panel or DIN-rail style
Medium | Mouser / Digi-Key | U2 | INA228 current/voltage monitor board | 1 | each | 85 V bus capable; external shunt input | Adafruit 5832 | Buy | Primary metrology
Medium | Mouser / Digi-Key | U3 | TC74 temperature sensor | 1 | each | TC74A0-5.0VAT or matching I2C address | Microchip | Owned / verify | Temperature sensing
Medium | Mouser / Digi-Key | R1,R2 | I2C pull-up resistors | 4 | each | 4.7 kOhm; 1%; 0.25 W | Yageo metal film | Buy | Two installed plus two spares
Medium | Mouser / Digi-Key | Rg1 | MOSFET gate resistors | 4 | each | 100 Ohm; 1%; 0.25 W | Yageo metal film | Buy | One installed plus spares
Medium | Mouser / Digi-Key | Rpd1 | MOSFET gate pulldown resistors | 4 | each | 10 kOhm; 1%; 0.25 W | Yageo metal film | Buy | One installed plus spares
Medium | Mouser / Digi-Key | TB1 | DIN or barrier terminal blocks | 12 | positions | >=300 V; >=15 A; accepts 12-22 AWG | Phoenix / WAGO / equivalent | Buy | For organized enclosure wiring
Medium | Mouser / Digi-Key | LED-G | Green panel indicator | 1 | each | 12 V panel-mount indicator | Any industrial panel LED | Buy | ARM/ready indication
Medium | Mouser / Digi-Key | LED-R | Red panel indicator | 1 | each | 12 V panel-mount indicator | Any industrial panel LED | Buy | Fault/contactor indication
Medium | Anchor Electronics | W1-R | Red high-current wire | 15 | feet | 12 AWG stranded copper; 60 V or higher insulation | UL-listed hookup wire | Buy | Battery-positive/high-current path
Medium | Anchor Electronics | W1-B | Black high-current wire | 15 | feet | 12 AWG stranded copper; 60 V or higher insulation | UL-listed hookup wire | Buy | Battery-negative/high-current path
Medium | Anchor Electronics | W-CTRL | Control-power wire | 25 | feet | 18 AWG stranded; assorted colors | UL-listed hookup wire | Buy | 12 V coil and control wiring
Medium | Anchor Electronics | W-SIG | Signal wire | 25 | feet | 22 AWG stranded; assorted colors | UL-listed hookup wire | Buy | Logic and status wiring
Medium | Anchor Electronics | W-SHLD | Shielded sensor cable | 10 | feet | 22-24 AWG; 2 twisted pairs plus shield | Any suitable instrumentation cable | Buy | INA228/I2C/ADC sensing where needed
Medium | Anchor Electronics | J1 | Keyed battery connector pairs | 2 | complete pairs | Genuine XT60; >=60 V; current rating above 10 A | Amass XT60 | Buy | One installed set plus one spare/mating harness
Medium | Anchor Electronics | RT-PWR | Power ring terminals | 12 | each | For 12 AWG wire; stud size matched to hardware | Tinned copper, insulated | Buy after measuring studs | Measure contactor, shunt, switch, fuse studs first
Medium | Anchor Electronics | RT-SIG | Small ring/fork terminals | 20 | each | For 18-22 AWG wire; matched to terminal screws | Insulated crimp terminals | Buy | Control wiring
Medium | Anchor Electronics | FER-12 | 12 AWG ferrules | 20 | each | Sized for 12 AWG stranded wire | DIN ferrules | Buy | Terminal blocks only; not for stud lugs
Medium | Anchor Electronics | FER-18 | 18 AWG ferrules | 30 | each | Sized for 18 AWG stranded wire | DIN ferrules | Buy | Control wiring
Medium | Anchor Electronics | FER-22 | 22 AWG ferrules | 30 | each | Sized for 22 AWG stranded wire | DIN ferrules | Buy | Signal wiring
Medium | Anchor Electronics | HS1 | Heat-shrink tubing assortment | 1 | kit | 1/8 to 1/2 inch; 3:1 preferred | UL-rated kit | Buy | Insulation and strain relief
Medium | Anchor Electronics | CG-PWR | Power cable glands | 2 | each | Approx. PG13.5; verify against cable OD | Nylon strain-relief gland | Buy after cable OD check | Battery/load cable entries
Medium | Anchor Electronics | CG-SIG | Signal cable glands | 2 | each | Approx. PG9; verify against cable OD | Nylon strain-relief gland | Buy after cable OD check | USB/sensor/control entries
Medium | Other vendor | ENC1 | Metal enclosure | 1 | each | Approx. 16 x 12 x 6 inches minimum; grounded metal; removable panel | Hammond / Bud | Buy after layout check | Separate high-energy and logic sections
Medium | Anchor Electronics | DIN1 | DIN rail | 1 | 12-inch length | 35 mm top-hat DIN rail | Standard aluminum/steel | Buy | Cut to enclosure layout
Medium | Anchor Electronics | GND1 | Chassis grounding stud/hardware | 1 | assembly | M5 or M6 stud with star washers and ground label | Stainless hardware | Buy | Dedicated protective-earth point
Medium | Anchor Electronics | COVER | Insulating terminal covers | 1 | set | Covers all exposed studs on fuse, disconnect, contactor and shunt | Matched boots/covers | Buy after hardware selection | Touch protection
Low | Anchor Electronics | SLEEVE | Braided cable sleeve | 10 | feet | 1/4 to 1/2 inch assortment | PET expandable sleeve | Buy | Wire organization
Low | Anchor Electronics | TIES | Cable ties and tie mounts | 1 | pack | Mixed small/medium sizes | UL-rated preferred | Buy | Wire management
Low | Anchor Electronics | HW-M3 | M3 standoffs and screws | 8 | sets | 10-15 mm standoff length | Nylon or metal as appropriate | Buy | Mount control boards
Low | Anchor Electronics | HW-M4/M5 | M4/M5 mounting hardware | 1 | assortment | Screws, locknuts, flat and star washers | Stainless/zinc-plated | Buy | Mount power components
Hold | Mouser / Digi-Key | TVS1 | Pack-input TVS protection | 1 | each | Exact standoff/clamp/pulse rating must follow transient analysis | TBD | DO NOT ORDER YET | Protection design unfinished
Hold | Mouser / Digi-Key | ADC-R | Redundant ADC divider resistors | 1 | set | Exact values, tolerance, power and voltage rating pending calculation | TBD | DO NOT ORDER YET | Analog divider unfinished
Hold | Mouser / Digi-Key | ADC-PROT | ADC protection and RC parts | 1 | set | Exact diode/capacitor/resistor values pending calculation | TBD | DO NOT ORDER YET | Analog protection unfinished
Owned | Existing equipment | U1 | STM32 Nucleo-L476RG | 1 | each | NUCLEO-L476RG | STMicroelectronics | Owned | Verify board condition
Owned | Existing equipment | LOAD | Programmable electronic load | 1 | each | At least 42 V and 10 A operating capability | Existing equipment | Owned | Verify actual power rating
Owned | Existing equipment | BENCH | Bench power supply | 1 | each | For development/testing only | Existing equipment | Owned | Not a substitute for final control PSU

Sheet: Summary
OSBAMS Final-Design Purchasing Summary
Category | Count
High-priority line items | 15
Medium-priority line items | 26
Low-priority line items | 4
Hold / unfinished line items | 3
Already-owned line items | 3
Important design basis
Battery under test | 10S NMC
Maximum pack voltage | 42 V
Target discharge current | Up to approximately 10 A
Control voltage | 12 VDC
Safety note | Do not order HOLD items until exact ratings/part numbers are finalized.

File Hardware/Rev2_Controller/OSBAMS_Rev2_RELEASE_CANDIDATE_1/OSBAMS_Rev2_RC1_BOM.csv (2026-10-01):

Item | Reference(s) | Qty / board | Qty for 5 boards | Value | Description | Manufacturer | MPN | MPN suffix status | Package | Footprint | Evidence Status | Lifecycle | Primary Supplier | Supplier SKU | Stock Check Date | Approved Alternate | PCBWay Source / Consign | DNP | Notes
1 | J1 | 1 | 5 | 12V_IN | 2-pos 5.00 mm right-angle screw terminal, 8 A / 300 V (footprint from Adam Tech drawing EB21A-XX-C rev B) | Adam Tech | EB21A-02-C | confirmed (Adam Tech drawing EB21A-XX-C, read locally; owned part) | EB21A-02-C | OSBAMS_Rev2:EB21A-02-C | USER_RELAYED_MANUFACTURER | UNKNOWN (not checked) | Mouser / Digi-Key (authorized) - NOT QUERIED | NOT CHECKED (distributor sites unreachable from the build environment) | NOT CHECKED | Phoenix MKDS 1/2-5,08 (different footprint) (UNVERIFIED alternate) | CONSIGN (owned: 5) or PCBWay source | no | Pin 1 +12 V, pin 2 GND. XDR-75-12 set to 12.0 V
2 | F1 | 1 | 5 | 1A fast | 1 A fast fuse 1206 32 V | Littelfuse | 0453001.MR | orderable suffix NOT yet confirmed against a distributor/manufacturer listing | 1206 | Fuse:Fuse_1206_3216Metric | UNVERIFIED | UNKNOWN (not checked) | Mouser / Digi-Key (authorized) - NOT QUERIED | NOT CHECKED (distributor sites unreachable from the build environment) | NOT CHECKED | Littelfuse 0466001.NR (UNVERIFIED alternate) | PCBWay source | no
3 | D2 | 1 | 5 | SS14 | 1 A 40 V Schottky SMA (series reverse-polarity) | Vishay | SS14-E3/61T | orderable suffix NOT yet confirmed against a distributor/manufacturer listing | SMA | Diode_SMD:D_SMA | UNVERIFIED | UNKNOWN (not checked) | Mouser / Digi-Key (authorized) - NOT QUERIED | NOT CHECKED (distributor sites unreachable from the build environment) | NOT CHECKED | Diodes Inc SS14-13-F (UNVERIFIED alternate) | PCBWay source | no
4 | D1 | 1 | 5 | SMBJ15A | Unidirectional TVS 15 V standoff 600 W (K = pin 1) | Littelfuse | SMBJ15A | orderable suffix NOT yet confirmed against a distributor/manufacturer listing | SMB | Diode_SMD:D_SMB | USER_RELAYED_MANUFACTURER | UNKNOWN (not checked) | Mouser / Digi-Key (authorized) - NOT QUERIED | NOT CHECKED (distributor sites unreachable from the build environment) | NOT CHECKED | Bourns SMBJ15A-Q (UNVERIFIED alternate) | CONSIGN or PCBWay source | no
5 | C1, C2 | 2 | 10 | 10uF 50V | 10 uF 50 V X7R 1210 (12 V rail / buck input) | Murata | GRM32ER71H106KA12L | orderable suffix NOT yet confirmed against a distributor/manufacturer listing | 1210 | Capacitor_SMD:C_1210_3225Metric | UNVERIFIED | UNKNOWN (not checked) | Mouser / Digi-Key (authorized) - NOT QUERIED | NOT CHECKED (distributor sites unreachable from the build environment) | NOT CHECKED | TDK C3225X7R1H106K250AC (UNVERIFIED alternate) | PCBWay source | no
6 | U3 | 1 | 5 | LMR14006Y | LMR14006Y 4-40 V 0.6 A 2.1 MHz buck SOT-23-6 (PIN MAP UNVERIFIED) | Texas Instruments | LMR14006YDDCR | orderable suffix NOT yet confirmed against a distributor/manufacturer listing | SOT-23-6 | Package_TO_SOT_SMD:SOT-23-6 | USER_RELAYED_MANUFACTURER | ACTIVE (user-confirmed) | Mouser / Digi-Key (authorized) - NOT QUERIED | NOT CHECKED (distributor sites unreachable from the build environment) | NOT CHECKED | LMR14006XDDCR (700 kHz variant: inductor change) (UNVERIFIED alternate) | PCBWay source | no
7 | C3, C8, C10, C11, C12, C13, C14, C17, C18, C21, C23, C24, C25, C27, C29, C32, C33, C34 | 18 | 90 | 100nF | 100 nF 50 V X7R 0603 | Murata | GRM188R71H104KA93D | orderable suffix NOT yet confirmed against a distributor/manufacturer listing | 0603 | Capacitor_SMD:C_0603_1608Metric | UNVERIFIED | UNKNOWN (not checked) | Mouser / Digi-Key (authorized) - NOT QUERIED | NOT CHECKED (distributor sites unreachable from the build environment) | NOT CHECKED | Samsung CL10B104KB8NNNC (UNVERIFIED alternate) | PCBWay source | no | At J7; INA228 VS; ISO7721 VCC1; ISO7721 VCC2; VBAT pin 1; VDD pin 19; VDD pin 32; VDD pin 64; VDDA; VDDUSB pin 48
8 | C4 | 1 | 5 | 100nF (bootstrap) | 100 nF 50 V X7R 0603 | Murata | GRM188R71H104KA93D | orderable suffix NOT yet confirmed against a distributor/manufacturer listing | 0603 | Capacitor_SMD:C_0603_1608Metric | UNVERIFIED | UNKNOWN (not checked) | Mouser / Digi-Key (authorized) - NOT QUERIED | NOT CHECKED (distributor sites unreachable from the build environment) | NOT CHECKED | Samsung CL10B104KB8NNNC (UNVERIFIED alternate) | PCBWay source | no
9 | L1 | 1 | 5 | 10uH | 10 uH shielded inductor 6x6 mm (10 uH +/-20 %, DCR 52 mohm, Irms 3.2 A, Isat 4.6 A: Bourns datasheet read locally) | Bourns | SRN6045TA-100M | confirmed (Bourns datasheet table, read locally) | L_Bourns_SRN6045TA | Inductor_SMD:L_Bourns_SRN6045TA | VERIFIED_LOCAL | UNKNOWN (not checked) | Mouser / Digi-Key (authorized) - NOT QUERIED | NOT CHECKED (distributor sites unreachable from the build environment) | NOT CHECKED | Wurth 744043100 (UNVERIFIED alternate) | PCBWay source | no
10 | R1 | 1 | 5 | 33.2k | 33.2k 1 % thick film 0603 | Vishay Dale | CRCW060333K2FKEA | orderable suffix NOT yet confirmed against a distributor/manufacturer listing | 0603 | Resistor_SMD:R_0603_1608Metric | UNVERIFIED | UNKNOWN (not checked) | Mouser / Digi-Key (authorized) - NOT QUERIED | NOT CHECKED (distributor sites unreachable from the build environment) | NOT CHECKED | Yageo RC0603-FR-07 series (UNVERIFIED alternate) | PCBWay source | no
11 | R2, R6, R16, R22, R37 | 5 | 25 | 10k | 10k 1 % thick film 0603 | Vishay Dale | CRCW060310K0FKEA | orderable suffix NOT yet confirmed against a distributor/manufacturer listing | 0603 | Resistor_SMD:R_0603_1608Metric | UNVERIFIED | UNKNOWN (not checked) | Mouser / Digi-Key (authorized) - NOT QUERIED | NOT CHECKED (distributor sites unreachable from the build environment) | NOT CHECKED | Yageo RC0603-FR-07 series (UNVERIFIED alternate) | PCBWay source | no | Bleeds the isolated clamp rail; Default OFF
12 | R3, R31 | 2 | 10 | 100k | 100k 1 % thick film 0603 | Vishay Dale | CRCW0603100KFKEA | orderable suffix NOT yet confirmed against a distributor/manufacturer listing | 0603 | Resistor_SMD:R_0603_1608Metric | UNVERIFIED | UNKNOWN (not checked) | Mouser / Digi-Key (authorized) - NOT QUERIED | NOT CHECKED (distributor sites unreachable from the build environment) | NOT CHECKED | Yageo RC0603-FR-07 series (UNVERIFIED alternate) | PCBWay source | no
13 | C5, C6 | 2 | 10 | 22uF | 22 uF 10 V X5R 0805 (derates ~50 % at 3.3 V) | Murata | GRM21BR61A226ME44L | orderable suffix NOT yet confirmed against a distributor/manufacturer listing | 0805 | Capacitor_SMD:C_0805_2012Metric | UNVERIFIED | UNKNOWN (not checked) | Mouser / Digi-Key (authorized) - NOT QUERIED | NOT CHECKED (distributor sites unreachable from the build environment) | NOT CHECKED | Samsung CL21A226MPQNNNE (UNVERIFIED alternate) | PCBWay source | no
14 | FB1 | 1 | 5 | 600R@100MHz | Ferrite bead 600 ohm @ 100 MHz 0603 | Murata | BLM18PG601SN1D | orderable suffix NOT yet confirmed against a distributor/manufacturer listing | 0603 | Inductor_SMD:L_0603_1608Metric | UNVERIFIED | UNKNOWN (not checked) | Mouser / Digi-Key (authorized) - NOT QUERIED | NOT CHECKED (distributor sites unreachable from the build environment) | NOT CHECKED | TDK MMZ1608B601CTAH0 (UNVERIFIED alternate) | PCBWay source | no
15 | C7, C15, C20, C22 | 4 | 20 | 4.7uF | 4.7 uF 10 V X5R 0805 | Murata | GRM21BR61A475KA73L | orderable suffix NOT yet confirmed against a distributor/manufacturer listing | 0805 | Capacitor_SMD:C_0805_2012Metric | UNVERIFIED | UNKNOWN (not checked) | Mouser / Digi-Key (authorized) - NOT QUERIED | NOT CHECKED (distributor sites unreachable from the build environment) | NOT CHECKED | Samsung CL21A475KPFNNNE (UNVERIFIED alternate) | PCBWay source | no | CP2102N VDD: 4.7 uF + 0.1 uF required per power pin (Silicon Labs datasheet, read locally)
16 | R4 | 1 | 5 | 3.3k | 3.3k 1 % thick film 0603 | Vishay Dale | CRCW06033K30FKEA | orderable suffix NOT yet confirmed against a distributor/manufacturer listing | 0603 | Resistor_SMD:R_0603_1608Metric | UNVERIFIED | UNKNOWN (not checked) | Mouser / Digi-Key (authorized) - NOT QUERIED | NOT CHECKED (distributor sites unreachable from the build environment) | NOT CHECKED | Yageo RC0603-FR-07 series (UNVERIFIED alternate) | PCBWay source | no | Permanent bleeder: keeps 3V3A < 1 V if PACK+ back-feeds through PA1 with the board unpowered
17 | R5, R7, R20, R32, R40 | 5 | 25 | 1k | 1k 1 % thick film 0603 | Vishay Dale | CRCW06031K00FKEA | orderable suffix NOT yet confirmed against a distributor/manufacturer listing | 0603 | Resistor_SMD:R_0603_1608Metric | UNVERIFIED | UNKNOWN (not checked) | Mouser / Digi-Key (authorized) - NOT QUERIED | NOT CHECKED (distributor sites unreachable from the build environment) | NOT CHECKED | Yageo RC0603-FR-07 series (UNVERIFIED alternate) | PCBWay source | no | CP2102N RSTb 1 kOhm pull-up to VDD (Silicon Labs datasheet 2.1, read locally)
18 | D3 | 1 | 5 | 3V3 ON | LED green 0805 | Wurth Elektronik | 150080GS75000 | orderable suffix NOT yet confirmed against a distributor/manufacturer listing | 0805 | LED_SMD:LED_0805_2012Metric | UNVERIFIED | UNKNOWN (not checked) | Mouser / Digi-Key (authorized) - NOT QUERIED | NOT CHECKED (distributor sites unreachable from the build environment) | NOT CHECKED | Kingbright APT2012SGC (UNVERIFIED alternate) | PCBWay source | no
19 | U1 | 1 | 5 | STM32L476RGT6 | STM32L476RG MCU LQFP-64 | STMicroelectronics | STM32L476RGT6 | orderable suffix NOT yet confirmed against a distributor/manufacturer listing | LQFP-64 | Package_QFP:LQFP-64_10x10mm_P0.5mm | USER_RELAYED_MANUFACTURER | UNKNOWN (not checked) | Mouser / Digi-Key (authorized) - NOT QUERIED | NOT CHECKED (distributor sites unreachable from the build environment) | NOT CHECKED | STM32L476RGT6TR (reel) (UNVERIFIED alternate) | PCBWay source | no
20 | C16 | 1 | 5 | 1uF | 1 uF 16 V X7R 0805 | Murata | GRM21BR71C105KA01L | orderable suffix NOT yet confirmed against a distributor/manufacturer listing | 0805 | Capacitor_SMD:C_0805_2012Metric | UNVERIFIED | UNKNOWN (not checked) | Mouser / Digi-Key (authorized) - NOT QUERIED | NOT CHECKED (distributor sites unreachable from the build environment) | NOT CHECKED | Samsung CL21B105KOFNNNE (UNVERIFIED alternate) | PCBWay source | no | VDDA
21 | SW1 | 1 | 5 | RESET | Tactile switch (reset) | C&K | PTS810SJM250SMTRLFS | orderable suffix NOT yet confirmed against a distributor/manufacturer listing | SW_SPST_PTS810 | Button_Switch_SMD:SW_SPST_PTS810 | UNVERIFIED | UNKNOWN (not checked) | Mouser / Digi-Key (authorized) - NOT QUERIED | NOT CHECKED (distributor sites unreachable from the build environment) | NOT CHECKED | Wurth 434121025816 (UNVERIFIED alternate) | PCBWay source | no
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

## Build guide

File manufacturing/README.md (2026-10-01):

# manufacturing/

**No fabrication or assembly package exists. This is intentional.**

The earlier PCBWay "candidate" package (commit `d400e2d`) was removed: it described the unrevised board, which has a critical diode-polarity defect and
a scope gap, and it was generated without KiCad. Final Gerber/BOM/CPL/PDF files may be generated **only** when every gate in
`docs/rev2/pcb/RELEASE_GATES.json` is true (blockers closed, HIGH items closed or dispositioned, ERC clean, DRC clean, BOM with manufacturer + exact MPN
for every populated part, Rev.1 physical observations recorded). `tools/mfg/build_package.py` refuses to run otherwise and
`tests/test_pcb_release_gates.py` fails if fabrication files appear while a gate is open.

See `docs/rev2/pcb/README.md`.

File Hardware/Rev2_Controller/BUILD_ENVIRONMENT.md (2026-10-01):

# Build environment for OSBAMS Rev.2 RC1

RC1 is generated by scripts (not by hand-editing KiCad files) so every output can be reproduced and checked.

- **KiCad 10.0.6** (matches the file format of the owner's KiCad 10) is obtained from the official `kicad/kicad:10.0.6` Docker image by `tools/pull_kicad_image.py` (registry API, no docker daemon), unpacked in `/opt/kicad10`, and used through `tools/kc10` (chroot with this repo bind-mounted at `/work`). Inside it the build uses `kicad-cli` (ERC, DRC, Gerber/drill/pos/PDF export) and the `pcbnew` Python API.
- **Autorouter**: Freerouting 1.9.0 (jar from the Freerouting GitHub release) run under `xvfb-run`; KiCad DSN/SES exchange via `design/route.py`.
- **Host Python** (3.12 + openpyxl, reportlab, matplotlib, cairosvg) builds the BOM/PDF/report files.
- The manufacturer websites (st.com, ti.com, vishay.com, ...) are **not reachable** from the build environment (HTTP 403 policy denial), which is why the evidence register has no VERIFIED_LOCAL manufacturer entries.

Rebuild order (see `build_rc1.py`): `design/build_sch` -> `sch upgrade` -> ERC -> `design/pcbgen` -> DSN -> Freerouting -> SES import + zone fill -> DRC -> export Gerber/drill/pos/PDF -> `design/reports`.

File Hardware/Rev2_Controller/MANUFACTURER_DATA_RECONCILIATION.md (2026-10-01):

# OSBAMS Rev.2 RC1 — manufacturer data reconciliation

Input: "MANUFACTURER DATA VERIFICATION INPUT" (user message, 2026-10-01): official manufacturer data retrieved by the user's web-capable reviewer.
**Evidence state for every row: `USER_RELAYED_MANUFACTURER`** — the build environment has not opened any of these PDFs, so nothing here is `VERIFIED_LOCAL`. The relayed values were used as authoritative inputs to compare the symbols, nets, footprints and calculations. This is a review package, not a fabrication release.

Update (RC1.1): the user then supplied the ISO7721, CP2102N and SRN6045TA datasheets; those three rows are now **VERIFIED_LOCAL** (read by the build). The ISO7721 row was a real mismatch (fixed), and reading the CP2102N datasheet added two further required changes (RSTb pull-up, 4.7 µF VDD bypass). All other rows remain USER_RELAYED_MANUFACTURER.

Update (RC1.2e): the TI INA228 datasheet SLYS021A (rev. May 2022) was supplied and read — pin map, absolute maximum ratings (differential ±40 V, CM and VBUS −0.3…85 V, 5 mA per pin), ZVBUS 0.8–1.2 MΩ, RDIFF 92 kΩ (active mode only), bias 2.5 nA, offset ±1 µV, SHUNT_CAL equation (×4 for ADCRANGE 1) are now **VERIFIED_LOCAL**; no mismatch with the symbol or the firmware (IMAX 20 A / SHUNT_CAL 1250). Panasonic ERJP08 (125 V / 500 V) and Littelfuse SMF12CA values remain USER_RELAYED.

Original audit result: **no pin-map mismatch was found on the board**, with **one unresolved conflict (ISO7721)** that could not be settled from relayed text alone. Two calculations were corrected (LMR14006Y minimum on-time, 1.5SMBJ48A vs INA228 85 V) and one firmware constant was changed (INA228 IMAX 30 A → 20 A, SHUNT_CAL 1875 → 1250). (RC1.0 audit: no electrical change; RC1.1: schematic and PCB regenerated and re-routed for ISO7721, CP2102N VBUS divider, R40, C22.)

| # | Component | Manufacturer | Existing symbol pin map | Manufacturer pin map (relayed) | Existing footprint | Manufacturer package | Electrical assumptions checked | Manufacturer values (relayed) | Result | Action taken | Evidence |
|---|---|---|---|---|---|---|---|---|---|---|---|
| 1 | INA228AIDGSR (U2) | Texas Instruments | 1 A1, 2 A0, 3 ALERT, 4 SDA, 5 SCL, 6 VS, 7 GND, 8 VBUS, 9 IN−, 10 IN+ | identical | `MSOP-10_3x3mm_P0.5mm` | DGS, VSSOP-10 | ADCRANGE 0, IMAX 20 A, SHUNT_CAL, 85 V limits | VS 2.7–5.5 V; CM/VBUS −0.3…+85 V; ±163.84 / ±40.96 mV; offset ±1 µV; bias 2.5 nA | **PASS** | Netlist pins A1/A0→GND, ALERT, SDA1/SCL1, VS→3V3_A, VBUS→INA_VBUS (via 10 Ω), IN−/IN+ → Kelvin nets: all consistent. SHUNT_CAL = 13107.2e6 × (20/2^19) × 2.5 mΩ = **1250** confirmed. ADCRANGE 1 rejected (40.96 mV / 2.5 mΩ = 16.4 A < 18.5 A trip). **Firmware changed**: `OSBAMS_INA228_IMAX_MA` 30000 → **20000** (`Firmware/Core/Inc/app_config.h`), regression test added (`test_ina228_calibration.c`, compiled-in config gives 1249–1251 with integer arithmetic). Desktop `INA228_SHUNT_MILLIOHM = 2.0` in `desktop/config.py` is a Rev.1-era placeholder (not changed here). | UR |
| 2 | STM32L476RGT6 (U1) | STMicroelectronics | PA0 14, PA1 15, PA2 16, PA3 17, PC8 39, PC9 40, PC10 51, PA13 46, PA14 49, PB3 55, BOOT0 60, PB8 61, PB9 62, PB10 29, PB11 30 | identical (standard LQFP64, not the SMPS variant) | `LQFP-64_10x10mm_P0.5mm` | LQFP64 | PA1 ADC protection, PC10 ARM divider, VREFINT | PA1 FT_la/ADC12_IN6 (not 5 V tolerant while the analog switch is connected); PC10 FT_l; TTL VIH 2.0 V / VIL 0.8 V; CMOS VIL 0.3 VDD; VREFINT 1.182–1.232 V, per-device factory calibration | **PASS** | ADC protection network (VCLAMP) retained — it does not rely on 5 V tolerance. ARM divider gives 2.84 V at 10.5 V > 2.0 V (TTL) and > 0.7 VDD. **Firmware note:** use the factory VREFINT calibration constant, not a nominal 1.212 V. POR threshold and VDD max were not relayed → stay UNVERIFIED. | UR (library pin numbers VERIFIED_LOCAL) |
| 3 | IRLML0060TRPBF (Q1) | Infineon | pad 1 G, 2 S, 3 D (netlist: GATE / GND / COIL_SW) | 1 G, 2 S, 3 D | `SOT-23` | Micro3 / SOT-23 | VDS margin, gate drive at 3.3 V, dissipation | VDS 60 V; VGS ±16 V; VGS(th) 1.0–2.5 V; RDS(on) ≤ 116 mΩ @4.5 V, ≤ 92 mΩ @10 V; **RDS(on) not guaranteed at 3.3 V** | **PASS** (pinout, ratings) / **OPEN** (3.3 V drive) | No guaranteed 3.3 V RDS(on) was invented; the pessimistic 0.5 Ω placeholder stays (0.17 A → 85 mV, 14 mW). Overdrive at 3.2 V vs VGS(th) max 2.5 V is 0.7 V. The relayed statement that Infineon's typical curves include 3.0/3.3 V makes the load plausible but is not a guarantee → first-article VDS / coil-current measurement is the validation item (`q_curves`, relayed). Plain flyback diode kept; no fast-release TVS. | UR |
| 4 | LMR14006YDDCR (U3) | Texas Instruments | 1 CB, 2 GND, 3 FB, 4 EN(/SHDN), 5 VIN, 6 SW | identical (pin 4 is /SHDN) | `SOT-23-6` (0.95 mm pitch) | DDC TSOT-6 | Vout min/max, TON_MIN, VIN limits | VIN 4–40 V (abs 45 V); fsw 1.785/2.100/2.415 MHz; VFB 0.747/0.765/0.782 V; ILIM ≈ 1.2 A; **TON_MIN 95 ns**; Dmax ≈ 97 % | pins **PASS**; calculation **CHANGE_REQUIRED (done)** | Vout range 3.178–3.431 V (VFB and 1 % resistors). Minimum on-time: 12 V → 131 ns typ / 114 ns at max fsw **PASS**; 15 V → 105 ns typ but **91 ns at max fsw (below 95 ns, marginal)**; 24.4 V TVS-transient → **64 ns (56 ns at max fsw), below TON_MIN → fixed-frequency regulation is no longer claimed; pulse skipping is expected**, behaviour there not characterised. Claim limited to ≈ 14.4 V (max-fsw) / 16.6 V (typ) steady-state input; normal source is the 12.0 V XDR. TSOT-6 vs KiCad SOT-23-6: pitch/pin numbering match, TI land pattern not compared. **SRN6045TA-100M Isat/DCR still unchecked (not relayed).** | UR |
| 5 | ISO7721DR (U7) | Texas Instruments | **was** 1 VCC1, 2 INA, 3 OUTB, 4 GND1, 5 GND2, 6 INB, 7 OUTA, 8 VCC2 (the ISO7720 table) → **now** 1 VCC1, 2 OUTA, 3 INB, 4 GND1, 5 GND2, 6 OUTB, 7 INA, 8 VCC2 | 1 VCC1, 2 OUTA, 3 INB, 4 GND1, 5 GND2, 6 OUTB, 7 INA, 8 VCC2 (Table 5-1 / Fig. 5-4, SLLSEP3G) | `SOIC-8_3.9x4.9mm_P1.27mm` | SOIC (D) 8, 4.90 × 3.91 mm; ISO7721DR Active | UART mapping, supplies, default output | VCC1/VCC2 2.25–5.5 V; default output HIGH without suffix | **MISMATCH → FIXED (RC1.1)** | The user-relayed table was right and the earlier symbol (from the ISO7720 table) was wrong. Symbol corrected; nets: OUTA(2)→UART_RX_MCU, INB(3)←UART_TX_MCU, OUTB(6)→UART_RX_HOST (CP2102N RXD), INA(7)←UART_TX_HOST (CP2102N TXD). Four UART nets re-routed; ERC/DRC/netlist/isolation re-run. | **VERIFIED_LOCAL** (datasheet PDF read; `docs/rev2/pcb/evidence/ISO7721_datasheet_SLLSEP3G.pdf`) |
| 6 | CP2102N-A02-GQFN20 (U6) | Silicon Labs | 1 GPIO.1, 2 GPIO.0, 3 GND, 4 D+, 5 D−, 6 VDD, 7 VREGIN, 8 VBUS, 9 RSTb, 10 NC, 11 SUSPENDb, 12 GND, 13 WAKEUP, 14 SUSPEND, 15 CTS, 16 RTS, 17 RXD, 18 TXD, 19 GPIO.3, 20 GPIO.2, EP GND | identical (section 5.3) | `SiliconLabs_QFN-20-1EP_3x3mm_P0.5mm_EP1.8x1.8mm` | QFN20 3×3 | VBUS divider, RSTb, bypass, regulator capability | VBUS needs a divider (22.1 k / 47.5 k in the reference); VIH = VIO−0.6 V; abs max VIO+2.5 V; VREGIN 3.0–5.25 V; VDD 3.1–3.6 V; IREGOUT 100 mA total; 1 kΩ RSTb pull-up; 4.7 µF + 0.1 µF per power pin | pins **PASS**; **CHANGE_REQUIRED ×3 (done, RC1.1)** | (1) VBUS: direct connection replaced by R38 22.1 kΩ / R39 47.5 kΩ (pin = 3.0–3.6 V; VBUS detected from 3.96 V typ, 4.40 V at VDD 3.6 V worst case = no margin at the USB minimum). (2) **New from reading the datasheet:** 1 kΩ pull-up on RSTb to VDD added (R40). (3) **New:** VDD bypass was 1 µF + 0.1 µF; datasheet requires 4.7 µF + 0.1 µF per power pin → C22 raised to 4.7 µF (10 V X5R 0805; effective capacitance after DC-bias derating to be confirmed). Regulator: 100 mA total vs ≈ 17 mA (device 9.5–13.7 mA + pull-up + ISO7721 ≈ 1–3 mA) → PASS. | **VERIFIED_LOCAL** (`docs/rev2/pcb/evidence/CP2102N_datasheet_rev1.5.pdf`) |
| 7 | VO610A-1 (U4, U5) | Vishay | 1 A, 2 K, 3 E, 4 C (netlist: ES_LED_A/FB_LED_A, GND, GND, ESTOP_SENSE/RELAY_FB) | 1 anode, 2 cathode, 3 emitter, 4 collector | `DIP-4_W7.62mm` | DIP-4 | CTR, VF, VCE(sat), temperature | CTR min 13 % / typ 30 % @1 mA; min 40 % / max 80 % @10 mA; VF max 1.6 V @50 mA; VCE(sat) max 0.3 V (IF 10 mA, IC 1 mA); VR 6 V; VCEO 70 V | **PASS** | Networks recomputed with VF max 1.6 V: ESTOP_SENSE 5.6 kΩ needs 10.0 V ≤ 10.5 V **PASS**; RELAY_FB 3 × 4.7 kΩ needs 22.7 V ≤ 24 V **PASS** (design floor 24 V, supported pack ≥ 30 V). The 0.8 temperature and 0.8 aging factors are now explicitly **DESIGN_MARGIN** (project assumptions, not manufacturer data). The 20 % CTR stays deleted. Surge dissipation shown for both 77.4 V and 100.6 V TVS levels. | UR |
| 8 | TC74A5-3.3VAT (probe U1) | Microchip | 1 NC, 2 SDA, 3 GND, 4 SCLK, 5 VDD | identical (tab = pin 3 = GND) | `TO-220-5_P3.4x3.7mm_StaggerOdd_Lead3.8mm_Vertical` | TO-220-5 | I²C2, supply, accuracy | 2.7–5.5 V; ±2 °C (25–85 °C) | **PASS** | No change. Note: the TO-220 tab is at GND (pin 3) — insulate it from the pack surface when mounting the probe. | UR |
| 9 | 1.5SMBJ48A (D5, D6, D7) | Bourns | n/a (diode) | K = pin 1 (checked by the polarity script) | `D_SMB` | SMB / DO-214AA | clamp vs INA228 85 V | VRWM 48 V; VBR 53.3–58.9 V; VC 77.4 V @19.4 A (10/1000 µs); **VC 100.6 V @97 A (8/20 µs)** | **CHANGE_REQUIRED → IMPLEMENTED in RC1.2 (series resistors R41 47 Ω, R42/R43 10 Ω upstream of D5-D7); model analysis PASS but NOT fully closed: ERJ-P08F pulse rating and 1.5SMBJ48A leakage unread** | "77.4 V < 85 V" is no longer used as a universal PASS. New §2b in the calculations: clamp vs current (estimate), VC = 85 V at ≈ 45 A. Bounded credible transients (≤ 19.4 A: load interruption at ≤ 18.5 A trip / 15 A fuse, hot-plug ringing) stay ≤ 77.4 V → margin ≥ 7.6 V. **Fast ≥ 45 A surges would exceed 85 V at the INA228 pins; this is a documented limitation and a sign-off item.** Optional mitigation (not applied): ≥ 47–100 Ω pulse-rated series resistor upstream of the TVS on PACK_INA; a stronger/two-stage clamp on the Kelvin lines. A lower-voltage TVS is rejected (standoff/leakage vs the 44 V ceiling). Owner decision required. | UR |
| 10 | Connectors J5, J6, J7, J8, J9 | Molex / JST / GCT / Samtec | KK-254 ×3 and ×4, PH ×4, USB4105 16P, 2×5 1.27 mm SMD | pitch/pin counts: KK 2.54 mm, PH 2.0 mm (A = 6.0 mm), FTSH 1.27 mm 2×5, USB4105 horizontal | KiCad stock | manufacturer drawings not available | pitch, pin count | KK 3/4 circuits, tail 3.56 mm, board 1.6 mm; PH 4 circuits; FTSH 10 pins keyed; USB4105 VBUS 5 A, signal 0.25 A | pitch/pin count **PASS**; geometry **OPEN** | Pad/drill/shield-pad/CC/pin-1/tail geometry cannot be compared with the numbers relayed (only pitch and counts were given) → `conn_footprints` stays UNVERIFIED/critical (needs the manufacturer drawings). | UR (pitch) / UV (geometry) |
| 11 | DG57CM-5021-76-1012-R (K1, external) | Durakool | coil via J4 (pin 1 COIL_V, pin 2 COIL_SW) | n/a | n/a | n/a | coil voltage/current | 12 VDC, 90 Ω ±10 %, operate ≤ 7.2 V, release ≥ 1.2 V; max coil 17.4 V @23 °C / **12.5 V @85 °C**; 60 A @36 VDC, 50 A @48 VDC | **PASS** | Coil current 121–148 mA at 12.0 V. Coil node ≈ 11.7 V (XDR 12.0 V, SS14 drop): operate margin 4.5 V; margin to the 12.5 V @85 °C limit only ≈ 0.8 V → XDR must stay at 12.0 V, never 15 V (15 V row marked as excluded). OSBAMS stays ≤ 44 V / ≤ 10 A. Diode-only flyback kept. | UR |
| 12 | SRN6045TA-100M (L1) | Bourns | n/a (inductor) | n/a | `L_Bourns_SRN6045TA` | 6×6 mm | saturation vs LMR14006Y current limit | 10 µH ±20 %, SRF 25 MHz, DCR 52 mΩ, Irms 3.20 A (40 °C rise), Isat 4.60 A (30 % inductance drop) | **PASS / CLOSED** | Isat 4.6 A is ≈ 3.8× the 1.2 A typical current limit and ≈ 20× the ≈ 0.22 A peak load current. Typical values only. | **VERIFIED_LOCAL** (`docs/rev2/pcb/evidence/SRN6045TA_datasheet.pdf`) |

## RC1.2 hardware/rule changes (after the independent review)
1. **Pack-sense protection:** R41 47 Ω on PACK_INA and R42/R43 10 Ω on the Kelvin lines, upstream of the 1.5SMBJ48A diodes; calculation §2b = PASS (credible set: TVS current ≤ 18.5 A → ≤ 76.5 V; hot-plug ≤ 60 V; limit 85 V).
2. **Isolation rule:** custom DRC rule ≥ 1.0 mm between any HOST-net item and any controller-net item on every layer (replaces the 0.25 mm zone clearance on the island edge); `ISOLATION_CHECK.txt`.
3. **Pack-level clearance:** 0.2 mm class (IPC-2221B B4 0.13 mm × 1.5) with an INA228-courtyard exemption.
4. Board re-routed; DRC 0 violations, 0 unconnected; netlist 0 mismatches (403 pads). Cosmetic silkscreen warnings fixed. Gerbers removed from the package.

## RC1.1 hardware changes (the reason this is a new RC)
1. **ISO7721 (U7) symbol corrected** to the TI D/DWV table (2 OUTA, 3 INB, 6 OUTB, 7 INA); UART nets re-assigned at the isolator (OUTA→MCU RX, INB←MCU TX, OUTB→CP2102N RXD, INA←CP2102N TXD).
2. **CP2102N VBUS divider**: R38 22.1 kΩ (VBUS_USB → CP_VBUS_SENSE), R39 47.5 kΩ (→ GND_HOST); U6 pin 8 now on CP_VBUS_SENSE; VREGIN stays on VBUS_USB.
3. **CP2102N RSTb pull-up** R40 1 kΩ to 3V3_HOST (datasheet §2.1, found while reading it).
4. **CP2102N VDD bypass** C22 1 µF → 4.7 µF (datasheet: 4.7 µF + 0.1 µF per power pin).
5. Board re-placed/re-routed; ERC 0; DRC 0 electrical (3 silkscreen warnings), 0 unconnected; netlist vs PCB 0 mismatches (397 pads); polarity none; isolation check (`ISOLATION_CHECK.txt`): **3.0 mm** GND↔GND_HOST in the ISO7721 area on all layers, 0.25 mm zone clearance along the remaining island edge.
6. Not changed: IRLML0060 (provisional; first-article VDS/coil-current measurement is the validation item), TVS protection (analysis + sign-off item).

## Corrected calculations (see `REV2_CALCULATIONS.md`)
- **A. LMR14006Y** — §3: min/typ/max-frequency on-time table against TON_MIN = 95 ns, Vout range from VFB 0.747–0.782 V and 1 % resistors, corrected 15 V / 24.4 V statements.
- **B. 1.5SMBJ48A** — §2b: clamp-vs-current analysis against the INA228 85 V maximum; credible-transient bound and its limits.

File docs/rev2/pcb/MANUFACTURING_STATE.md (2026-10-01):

# Manufacturing state — resolved

**Current state (2026-10-01): RELEASE CANDIDATE 1 exists for REVIEW (`Hardware/Rev2_Controller/OSBAMS_Rev2_RELEASE_CANDIDATE_1/`, KiCad 10 ERC 0 / DRC 0 electrical + 12 silk warnings). NOT authorized for fabrication — gates below remain false; its Gerber zip is marked NOT_FOR_FABRICATION.** Historical note: before RC1, No Gerber, drill, BOM, CPL or assembly output is in the repository.

| Source | Date | Claim | Verdict |
|---|---|---|---|
| `PCBWAY_READINESS_GAPS.md` (audit) | 2026-09-30 | No final Gerbers/BOM/CPL were generated | Correct when written |
| Candidate package `manufacturing/PCBWay_OSBAMS_Rev2_PCBA/` (script-generated, not KiCad export) | 2026-10-01 | A package exists | **Stale — removed.** It was built from the Rev.1 board, which carries the diode-polarity defect (G-01), so it would have fabricated a board that cannot work. |

Actions taken
- Whole candidate package removed (Gerbers, drill, BOM xlsx, CPL, PDFs, previews).
- Its two review documents are kept only as `REV1_BOARD_*_SNAPSHOT.md` (banner: historical).
- `RELEASE_GATES.json` holds six gates, all `false`. `python3 -m tools.mfg.build_package` refuses to run (exit non-zero, lists open gates) unless `--candidate` is passed.
- `tests/test_pcb_release_gates.py` fails if any fabrication file appears under `manufacturing/` while a gate is open.

Gates (set true only with evidence filed in this directory)
1. all BLOCKER items closed (G-01, G-02, G-05 …, see audit)
2. HIGH items closed or explicitly dispositioned
3. ERC clean (KiCad 10 run, report filed)
4. DRC clean (KiCad 10 run, report filed)
5. BOM: manufacturer + exact MPN on every populated part
6. Rev.1 physical observations recorded (bench sheet V1–V10 filed, truth inventory updated)

## Update 2026-10-01 (direction change)
Rev.1 KiCad source moved to `legacy/reference/rev1_kicad/` (reference only). Rev.2 is a new design in `Hardware/Rev2_Controller/`; no Rev.2 schematic, layout or manufacturing file exists yet. The six gates apply to the new board.

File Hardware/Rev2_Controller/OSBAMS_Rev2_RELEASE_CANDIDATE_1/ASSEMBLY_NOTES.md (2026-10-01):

# OSBAMS Rev.2 Controller — Assembly notes (2026-10-01)

**RC1.2e - REVIEW CANDIDATE - NOT RELEASED FOR FABRICATION.**

## Assembly summary
- 106 SMT/SMD-only footprints (top side) and 12 through-hole footprints (including connectors, 2 x VO610A-1 DIP-4, 2 x 1N4148 DO-35, JP1, mounting hole/test-point features are not parts).
- Parts are on the **top side only**; no bottom-side assembly. Test points are bare 1.5 mm pads (no component).
- **THT parts needing hand/selective soldering:** J1-J4 (Adam Tech EB21A-02-C), J5 (Molex 22-27-2031), J6 (22-27-2041), J7 (JST B4B-PH-K-S), JP1, U4/U5 (VO610A-1 DIP-4), D11/D12 (1N4148 DO-35), J9/J8 mixed SMT+THT shield.
- **Consigned vs sourced:** default is PCBWay-sourced. Owned parts that can be consigned (BOM column `PCBWay Source / Consign`): 2 x VO610A-1 (exactly the two needed), 2 x 1N4148, EB21A-02-C (5 owned, 4 needed), 1.5SMBJ48A (2 owned, 3 needed), SMBJ15A. VJ0805Y104JXXAT (2 owned) are used on the probe board.
- **Do not populate:** R1/R2 on the probe board (DNP). Everything on the controller BOM is fitted in the baseline (I2C2 pull-ups fitted).

## Polarity / orientation
- Diodes: pad 1 = cathode on every diode footprint (checked against the library geometry and the netlist; see `DFM_DFA_REPORT.md`). D1, D2, D5-D7, D9 SMA/SMB bars face pad 1; D11/D12 DO-35 band at pad 1 side; LEDs D3/D4/D10 pad 1 = cathode.
- U1 pin 1 dot top-left; U2 (MSOP-10) pin 1 dot; U3, U9, U10 SOT-23-6 pin 1; U6 QFN-20 pin 1 + exposed pad to GND_HOST; U7 SOIC-8 pin 1.
- J1-J4: pin 1 square pad, wire entry toward the board edge. Footprint `EB21A-02-C` follows the Adam Tech drawing (VERIFIED_LOCAL); the drawing does not number the pins, so pin 1 = the 2.50 mm end is a design convention.
- J5/J6/J7 are keyed (KK 254 / PH). J9 SWD is a shrouded keyed header. J8 USB-C front face overhangs the right edge by ~0.8 mm.

## CPL
`OSBAMS_Rev2_RC1_CPL.csv` (SMT) and `..._CPL_ALL.csv` use KiCad footprint-origin positions/rotations (mm, bottom-left origin, y up). **PCBWay's pick-and-place library rotation conventions differ for some packages (SOT-23-6, QFN-20, LQFP-64, SOIC-8, MSOP-10, diodes): verify every rotation in PCBWay's CAM preview before accepting.**

## First-article note
Build 2-3 boards. Bring-up order: power (+12V, 3V3, 3V3_A ripple), reset/SWD attach, 80 MHz clock, GPIO, I2C scan (INA228 0x40), UART echo through the isolator, feedback/E-stop/ARM readbacks, relay driver with the real K1 coil at 12.0 V.

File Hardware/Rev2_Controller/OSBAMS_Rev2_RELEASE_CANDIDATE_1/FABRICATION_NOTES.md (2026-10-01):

# OSBAMS Rev.2 Controller — Fabrication notes (2026-10-01)

**RC1.2e - REVIEW CANDIDATE - NOT RELEASED FOR FABRICATION.** These are working notes for the RC1 review package, not an order specification.

## Board
- Name `OSBAMS Rev.2 Controller`, revision RC1.2e, size 100 x 90 mm, single piece (no panelization specified yet), 4 copper layers, 1.6 mm FR-4 (TG >= 150 C suggested), outer copper 1 oz, inner copper 0.5 oz or 1 oz.
- Layer use: L1 components + signals, L2 solid GND plane, L3 routing + GND fill, L4 components/signals + GND fill. A separate **GND_HOST island** (isolated USB side) occupies x 74.5-97.5 mm, y 2.5-47.5 mm on all layers; **every host-net copper item keeps >= 1.0 mm from every controller-net copper item on every layer** (custom DRC rule in `OSBAMS_Rev2_RC1.kicad_dru`; 3.0 mm gap in the ISO7721 area). See `ISOLATION_CHECK.txt`.
- Finish: ENIG recommended (0.5 mm pitch LQFP-64, QFN-20). Soldermask green or black, white silkscreen. Lead-free.
- Edge: plain rectangle, no V-cut, 4 x M3 NPTH (3.2 mm) at (4,4), (96,4), (4,86), (96,86). 3 fiducials 1 mm / 2 mm mask opening.
- Design rules (netclasses in the .kicad_pro + custom rules in the .kicad_dru): default track 0.2 mm / clearance 0.15 mm; POWER 0.3 mm / 0.2 mm; RAIL 0.3 mm / 0.15 mm; **pack-level and Kelvin nets 0.2 mm clearance — a deliberate LOW-VOLTAGE SENSE-NET rule (sense circuitry up to the 44 V ceiling, ~77 V TVS clamp), NOT a general high-voltage clearance rule (an intentional choice: IPC-2221B Table 6-1, 31-100 V, B4 = external conductors under permanent polymer coating/solder mask = 0.13 mm, internal B1 = 0.1 mm; 0.2 mm is 1.5x B4 — exposed pads/terminations (A6 0.6 mm) cannot be met on 0.5 mm-pitch parts, so the INA228 courtyard is exempt at 0.15 mm)**; host-to-controller 1.0 mm; via 0.6/0.3 mm (0.5/0.3 mm in a few congested spots), min track 0.20 mm, copper-to-edge 0.3 mm. **PCBWay's current 4-layer minimum track/space/drill/annular-ring capability must be confirmed in their quote/DFM tool** (this build could not reach their site); the values above are well above the usual 0.1 mm / 0.2 mm drill minimums.
- Controlled impedance: none required (no high-speed nets; USB 2.0 full-speed D+/D- are short, 90 ohm not controlled in RC1 - review).
- Silkscreen: connector names, pin numbers, polarity, `OSBAMS Rev.2 Controller`, `RC1.2e 2026-10-01`, `44 V / 10 A MAX`, `NOT FOR FABRICATION` (remove at release by editing the text in KiCad before the final export).

## Files
This package contains **no Gerber or drill files**: the earlier script-generated candidate Gerbers were removed so they cannot be used by mistake. Export Gerbers/drills from the final `.kicad_pcb` in your own KiCad 10 after your local ERC/DRC (see `PRE_PCBWAY_RELEASE_CHECKLIST.md`).

## Open fabrication gates
See `PCBWAY_RELEASE_CANDIDATE_REPORT.md` (BLOCKERS BEFORE PCBWAY ORDER).

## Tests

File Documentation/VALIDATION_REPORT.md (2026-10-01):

# OSBAMS Validation Report

> **Rev.2 note:** Rev.2 validation is planned in `docs/rev2/PHYSICAL_VALIDATION_PLAN.md` (all rows NOT RUN). This Rev.1 report lists the Rev.1 electronic load as 'to be recorded'; the Rev.2 primary load is the 6060B.

**Build:** 0.9.0-dev1 — Engineering Prototype
**Date of this revision:** 2026-07-22
**Status:** Interim. Host-side verification is recorded below. Hardware
acceptance testing has not yet been performed and every hardware row is marked
NOT RUN, not passed.

This report is deliberately honest about what has and has not been demonstrated.
A row is only PASS if there is evidence for it in this build. Hardware-dependent
rows cannot pass until the fixture exists.

---

## 1. Test environment

| Item | Value |
|---|---|
| Firmware version | 0.9.0-dev1 |
| Desktop version | 0.9.0-dev1 |
| Protocol version | 1 |
| Database schema | 6 |
| Hardware | Engineering Prototype (not built/frozen) |
| Host test toolchain | gcc (firmware host tests), pytest (desktop) |
| Reference instruments | none yet — to be recorded when bench testing begins |

Instrument identity fields (electronic load make/model/serial, reference DMM,
controller serial, calibration due dates) are to be captured per test session
once hardware exists. They are empty now by necessity, not by omission.

---

## 2. Automated test results (host, no hardware)

These run on a clean checkout and are the evidence behind the "Host-tested"
column of `MODULE_STATUS.md`.

| Suite | Command | Result |
|---|---|---|
| Desktop + cross-language protocol | `pytest tests/` | 72 passed |
| Firmware measurement engine | `firmware/Tests` → `make` | 11 passed |
| Watchdog gating + ADC predicate + safety response | `firmware/Tests` → `make` | 10 passed |

What these prove: measurement math, scoring determinism, suitability logic,
protocol encode/decode byte-identical between C and Python, watchdog
subsystem-heartbeat gating policy, the ADC agreement predicate, and the Safety
Manager's response to a disagreement flag.

What these do NOT prove: any measurement is numerically correct against a
reference, any timing is met on hardware, or any physical safety action occurs.
Host compilation proves API consistency, not sensor correctness.

---

## 3. Acceptance test status

Mapped to the System Specification (§10). "Verifiable now" means the criterion
can be met at least partly by host tests; full sign-off still needs hardware for
anything touching a sensor, timer, or contactor.

| ID | Test | Requirement(s) | Status | Notes / evidence |
|---|---|---|---|---|
| ACC-01 | Boot and self-test | REQ-109 | NOT RUN | needs hardware; sensor health logic host-tested |
| ACC-02 | 60 s telemetry capture | REQ-104, REQ-108 | PARTIAL | frame format + sequence numbering host-verified; on-hardware period NOT RUN |
| ACC-03 | Known-load integration | REQ-105, REQ-106 | PARTIAL | Ah/Wh math host-verified vs synthetic data; reference-load comparison NOT RUN |
| ACC-04 | Overtemperature injection | REQ-201/205/206 | NOT RUN | fault + latch logic host-tested; physical response NOT RUN |
| ACC-05 | Undervoltage injection | REQ-202 | NOT RUN | logic host-tested; physical response NOT RUN |
| ACC-06 | Host disconnect during test | REQ-205, REQ-603 | NOT RUN | requires hardware |
| ACC-07 | Sensor disconnect | REQ-109 | NOT RUN | health-transition logic host-tested; physical NOT RUN |
| ACC-08 | Stuck I2C recovery | REQ-109 | NOT RUN | recovery routine implemented; bench NOT RUN |
| ACC-09 | Quarantine gate | REQ-207 | PASS | desktop test blocks start for QUARANTINE/FAIL |
| ACC-10 | Score determinism | REQ-302 | PASS | identical input → identical score (host test) |
| ACC-11 | Rule weight floor | REQ-304 | PASS | ML weight never exceeds 0.50 (host test) |
| ACC-12 | Report reproducibility | REQ-406 | PASS | report includes the full version block |
| ACC-13 | Database backup | REQ-405 | PARTIAL | backup-before-migration logic present; long-run NOT RUN |
| ACC-14 | Prediction retention | REQ-403 | PASS | prior predictions retained after re-assessment |
| ACC-15 | Endurance run (4–8 h) | REQ-104 | NOT RUN | requires hardware |
| ACC-16 | TIM6 acquisition timing | REQ-110, REQ-111 | NOT RUN | backlog-counter logic host-tested; period/jitter must be measured on a logic analyser |
| ACC-17 | Watchdog and safe reset | REQ-210, REQ-211 | PARTIAL | gating policy host-tested; real IWDG timeout, reset cause, safe-boot NOT RUN |
| ACC-18 | Redundant voltage cross-check | REQ-212, REQ-506 | PARTIAL | disagreement→fault path host-tested; INA228-vs-reference and real divergence NOT RUN |
| ACC-19 | Contactor and E-stop chain | REQ-213, REQ-214 | NOT RUN | requires hardware; this is the most important missing physical proof |

Summary: 6 PASS (all software-only), 6 PARTIAL (logic verified, hardware
pending), 7 NOT RUN. 0 of the hardware-dependent criteria are validated.

---

## 4. Calibration status

No channel has been calibrated. See `CALIBRATION.md` for the procedure and the
record tables to be filled in. No measurement tolerance is claimed anywhere in
this package because no calibration data supports one.

---

## 5. Deviations

None recorded yet — no hardware test has been run from which a deviation could
arise. This section will list any acceptance criterion that hardware testing
fails to meet, with the disposition.

---

## 6. Remaining limitations

Carried from `known_limitations.md`:

- INA228 software is implemented but uncalibrated and unverified on the part.
- The ADC redundant channel is a diverse cross-check, not a certified
  independent protection device (both channels share pack wiring and ground).
- Watchdog reset behaviour is not bench-validated.
- TIM6 timing accuracy and jitter are unverified until measured.
- Physical fault response (contactor de-energising on fault and on reset,
  E-stop independent of firmware) is unverified.

---

## 7. Conclusion

The software architecture is verified to the extent host testing allows. The
system is **not** validated as an instrument and must not be represented as one
until the hardware acceptance tests above are executed with recorded results.
This is why the build is `0.9.0-dev1` and not a release candidate.

When the hardware rows carry real PASS results and recorded data, this report —
with equipment, serial numbers, dates, procedures, raw data, and pass/fail —
becomes the evidence that justifies promotion to 0.9.0-rc1 and, after the
hardware is frozen, to 1.0.0 / Hardware Rev A.

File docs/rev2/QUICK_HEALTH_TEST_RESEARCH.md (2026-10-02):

# Quick Health Test — research design (no PCB change, not a production feature)

**Research stage. A full controlled discharge remains the ground truth. Nothing here is a health claim.**

Sequence (per battery, low energy, inside the existing current/power limits): **OCV → small load step → larger step → recovery**.
Candidate features (`ai/features/extract.py → quick_test_features`): OCV; ΔV/ΔI between the two steps; immediate voltage sag at the large
step; recovery slope after release; dynamic resistance; temperature; response times. All use the existing 6060B manual mode and the OSBAMS
telemetry; no new hardware.

Study plan: for every battery that gets a quick test, also run the full discharge and DCIR (separate test); store both in the dataset
(`DATASET_SCHEMA.md`); only then ask whether quick features predict capacity retention, with a split by battery identity
(`ai/evaluation/split.py`) and the validation metrics recorded in the model registry. Until such data exist the quick test is
exploratory; the rule-based triage (`ai/assessment/rule_baseline.py`) does not use it.

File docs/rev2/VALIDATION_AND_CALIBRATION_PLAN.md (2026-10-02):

# Validation and calibration layer (Rev.2)

**Status: software and procedures only. Nothing here has been run on hardware; no limit below is a validated specification.**
This layer sits *around* the frozen Rev.2 hardware (STM32L476RG, INA228, independent ADC channel, TC74, relay/E-stop/ARM chain,
Pi 5, SQLite). It changes no PCB. It follows the literature takeaways in `Documentation`: calibrated direct measurement first,
documented limitations for low-cost instruments, staged low-energy validation, and accurate current integration.

Related existing documents (this plan adds the software/data layer, it does not replace them): `INSTRUMENT_CALIBRATION_PLAN.md`, `LV_HARDWARE_VALIDATION_PLAN.md`, `BENCH_CHECKLIST.md`, `FIRST_BATTERY_TEST_PROCEDURE.md`, `CALIBRATION_RECORD_TEMPLATE.md`.

## 0. Where the strategy comes from (literature review — methods informed, not validated by)
The additions in this plan are derived from a literature review of battery-testing and low-cost-instrument papers. **The papers do not
validate OSBAMS**; their methods shaped the strategy: (1) calibrated direct measurement comes before any advanced SOH estimation; (2) low-cost
instruments must be validated against a reference instrument and their limits documented; (3) Raspberry-Pi/open-source testers are validated
against reference equipment; (4) testing is staged — low-energy and fault-injection first; (5) current integration needs accurate current and
accurate timing. Every limit in this plan is PROVISIONAL until OSBAMS' own reference data exist. Related: `PROTOCOL_V2_DESIGN.md`,
`DATASET_SCHEMA.md`, `QUICK_HEALTH_TEST_RESEARCH.md`, `WORKSTREAMS.md`, `ai/README.md`.

Workflow: **calibrate → validate against a reference → fault-inject → characterize packs → (later) learn from the data.**

## 1. What exists in the repo now

| Item | Where | Notes |
|---|---|---|
| Linear calibration fit, residual table, zero offset, profile + id | `desktop/services/calibration.py` | `corrected = gain*raw + offset`, separately for V and I; gain outside 0.90–1.10 is refused (wrong reference / wiring) |
| Calibration persistence, one active profile | `desktop/services/calibration_store.py`, table `calibrations` | applied to live samples in the dashboard; no profile → results flagged REVIEW REQUIRED |
| Ah/Wh integration with the actual sample spacing + agreement check | `desktop/services/charge_integration.py` | warns `CAPACITY_VALIDATION_WARNING` above the (provisional) limit |
| Measurement-quality report | `desktop/services/quality.py` | PASS / REVIEW REQUIRED; unavailable items are listed as not available, never silently passed |
| Capacity retention, repeatability, DCIR pulse maths | `desktop/services/metrics.py` | retention carries a "not a validated cell-level SOH" note |
| Provenance columns on `tests`, ADC/flags columns on `readings` | `desktop/db/migrations.py` | additive and idempotent |
| DCIR result records its conditions | `DcirTest.results().dcir_conditions` | OCV, step currents, pulse length, max temperature |
| Tests | `tests/test_validation_layer.py` | host-only |

**Not done (needs firmware / protocol work — separate, deliberate change):** the INA228 charge/energy accumulators, an STM32-side
accumulator and the independent ADC voltage are not in the v1 serial frame (`desktop/services/protocol.py`), so the three-way
integration currently has only the Pi total and the quality report lists the ADC cross-check as *not available*. Proposed protocol v2
adds `V_adc_mV`, `charge_uAh_ina`, `charge_uAh_mcu` (and the energy equivalents) with the same CRC scheme; it changes the frozen
safety-controller interface, so it needs its own review, firmware tests (`make -C Firmware/Tests run`) and a version bump. Also not
done: the Pi calibration/validation **screens** (`Settings → Calibration / Validation`); the service layer above is ready for them.

## 2. Calibration procedure (outside any battery test)
Use a reference instrument alongside OSBAMS (the EDU34450A is the reference in this project). Record instrument, operator, ambient temperature.

| Channel | Reference points | Record at each point |
|---|---|---|
| Voltage | 30, 34, 38, 42, 44 V (current-limited source, no battery) | reference V, INA228 V, ADC V (when available) |
| Current | 0 A first (zero offset), then 1, 2, 5, 8, 10 A | reference I, INA228 I |

Fit with `fit_linear`, store with `save_calibration` (id `CAL-YYYY-MM-DD-NN`), keep the residual table with the lab record
(`templates/calibration_points.csv`, `CALIBRATION_RECORD_TEMPLATE.md`). Re-calibrate when the shunt, INA228, cabling or board changes,
and after the limit on calibration age (provisional 90 days).

## 3. Reference-instrument validation (a lab procedure, not an OSBAMS feature)
After calibrating, check **different** points than were used for the fit and tabulate error against the reference
(`templates/reference_validation.csv`): reference, OSBAMS, error, error %. Set the quality limits (`QualityLimits`) from these results; until
then they are placeholders. Also run one full discharge with the EDU34450A integrating Ah in parallel and compare totals.

## 4. Three-way capacity integration
A. INA228 accumulators, B. STM32 accumulation of every measurement, C. Pi integration of the saved timestamped telemetry. Use the **measured**
time between samples. Report all three and the maximum disagreement; above the limit raise `CAPACITY_VALIDATION_WARNING`. Today only C is
available on hardware (§1). The host side of the full comparison exists (`services/capacity_validation.py`, protocol v2 reference parser,
golden vectors; design in `PROTOCOL_V2_DESIGN.md`); the firmware does not send v2 yet. The comparison stores Ah and Wh per method, % disagreement,
sample and missing-sample counts, calibration id, firmware version and PCB revision. The agreement threshold is provisional (default 1 %).
Pi reconstruction for the agreement uses raw samples (like-for-like with the device); the calibrated Pi result is reported separately.

## 5. DCIR (separate test)
`Start Test → Internal Resistance`: R = (V0 − V1) / (I1 − I0) with a fixed pulse length; always store state of charge/OCV, temperature,
current, pulse duration (done: `dcir_conditions`). A DCIR value without its conditions is not comparable between runs.

## 6. Capacity retention, not SOH
Show **capacity retention vs rated** (measured usable capacity / rated capacity from the profile) and the note that it is an
experimental pack-level assessment. Pack-terminal tests cannot see individual cell imbalance — state this limitation in every report.

## 7. Repeatability
Run the same pack three times under identical conditions; report mean, standard deviation, CV % and the maximum deviation %
(`metrics.repeatability`). Define "±x %" as the maximum deviation from the mean and say so.

## 8. Fault-injection suite (before any real pack; current-limited source, resistive load)
Record PASS/FAIL, date, operator, firmware version in `templates/fault_injection.csv`.

| # | Fault | Expected response | Result |
|---|---|---|---|
| 1 | E-stop pressed | relay drops immediately; load current falls to ~0 | |
| 2 | ARM off | load cannot energize | |
| 3 | INA228 absent / I²C fault | fault, load off | |
| 4 | TC74 absent | temperature fault, test refuses to start | |
| 5 | ADC vs INA228 disagreement | sensor fault (needs protocol v2) | |
| 6 | Pi disconnected / UART silent | STM32 stays safe (load off after the comm-loss timeout) | |
| 7 | UART corrupted (bad CRC) | frames rejected, no unsafe command | |
| 8 | Relay feedback wrong | latched relay fault | |
| 9 | Kelvin lead open | out-of-range shunt reading → sensor fault, load off | |
| 10 | Hot-plug of sense harness at 42–44 V | pins stay below limits; no calibration shift (controller audit F4) | |

The hardware first-article tests F1–F8 in `Hardware/Rev2_Controller/CONTROLLER_PROTECTION_AND_CONNECTOR_AUDIT.md` are part of this suite.

## 9. Database traceability
`tests` now also stores: calibration id, rated capacity, capacity retention %, measurement-quality status and JSON, firmware version, PCB
revision, sample/missing-sample counts, DCIR conditions, integration totals. `calibrations` stores every profile with its residuals.
`readings` has nullable `voltage_adc_mv` and `flags` columns, filled once the protocol carries them.

## 9b. User interface and data products
`Settings → Calibration` (voltage/current points, zero-current offset, reference instrument, active profile, fit and residuals) and
`Validation / Measurement Quality` (profile, gains/offsets, zero offset, ADC-vs-INA228 and integration agreement, missing samples,
PASS / REVIEW REQUIRED; unavailable items show NOT AVAILABLE) are in `desktop/gui/tabs/settings_tab.py`. Battery Passport and the open dataset
export: `DATASET_SCHEMA.md`.

## 10. Machine learning comes last
Collect labeled data first (capacity retention, DCIR with conditions, temperature, discharge-curve shape, voltage sag, pack type, repeated
tests over time). Do not present a trained model as validated until it has real labels and cross-validation; for the capstone, ML is future work. The `ai/` area holds only the infrastructure (rule-based baseline, feature definitions, group-by-battery
evaluation, explainable model zoo, registry); it refuses to train on too little validated data and is exercised with clearly-labelled synthetic data only.

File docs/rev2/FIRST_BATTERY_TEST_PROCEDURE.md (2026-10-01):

# First battery test procedure — Ninebot NEB1002-H (36 V, 5.2 Ah)

**Status: procedure only. Nothing here has been run; no result is claimed.** BENCH_TESTED may be
recorded only after the measurements in this procedure exist, with data stored (see `BENCH_CHECKLIST.md`,
`ValidationLog`). Use `HARDWARE_ACCEPTANCE_RECORD.md` and `CALIBRATION_RECORD_TEMPLATE.md` alongside this document.

```
Ninebot 36 V pack → XT60 → fuse → disconnect → relay → shunt → OSBAMS (INA228 / ADC / TC74) → Agilent 6060B → pack −
Reference: Keysight EDU34450A (voltage always; current in series only where stated)
Observation: Keysight EDUX1052G (timing / transients)
```

Measure and store: voltage, current, power, temperature, Ah, Wh, cutoff, recovery — then compare
OSBAMS voltage and current against the EDU34450A.

## 0. Numbers for this pack (from the code — `services/battery_profiles.py`, `config.py`)
| Item | Value |
|---|---|
| Pack | Ninebot/Segway NEB1002-H, nominal 36 V, max 42 V, rated 5.2 Ah / 187 Wh, lithium-ion NMC 10S |
| **Profile cutoff** | **30.0 V** (automatic stop) |
| Profile max voltage | 42.0 V (OSBAMS faults above 43.0 V) |
| Profile recommended / ceiling current | **1.0 A** / 5.2 A |
| 6060B power limit at 42 V / 36 V | 300 W / 42 V = **7.14 A** / 8.33 A |
| OSBAMS operating ceiling | **10 A, 44 V** (provisional) |
| **Final permitted current at 42 V** | min(5.2, 10, 60, 7.14) = **5.2 A** (limit: battery profile) — **the first runs use far less (0.5 A, then 1.0 A)** |
| Temperature stop | **50 °C** (OSBAMS); firmware hard trip 60 °C |
| Current layers | 10 A OSBAMS limit · 15 A fuse (abnormal fault current only) · 18.5 A firmware trip · 20 A shunt |
| Expected full run at 1.0 A | roughly 4–5 h, less for a degraded pack (energy ≈ 187 Wh × SOH) |

Allowed current = min(battery profile, OSBAMS hardware limit, 6060B current limit, 300 W / battery voltage), using the
**conservative** pack voltage (max of OCV and highest seen — sag never raises the current).

## 1. Preconditions (stop here if any is not true)
- [ ] `HARDWARE_ACCEPTANCE_RECORD.md` §2–§6 complete: installed part numbers read and recorded; fuse, disconnect, relay, shunt, XT60 identified.
- [ ] Bench steps **A1, A2, B1, B2, B3** PASS (records, power-path inspection, controller bring-up, source-free fault tests, relay coil-side timing) with data stored.
- [ ] A second person is present and the lab supervisor knows a Li-ion pack is being tested; eye protection on; non-conductive surface; no loose metal near the pack; Li-ion-appropriate extinguishing means known.
- [ ] E-stop within arm's reach of the operator; path to the 6060B front panel clear.
- [ ] OSBAMS software commit recorded: ____________   Tolerances for each comparison written in the calibration record **before** measuring.
- [ ] Registry row exists: chemistry NMC, cutoff 30 V, nominal 36 V, max charge 42 V, rated 5.2 Ah, safety status not Quarantine.

## 2. Battery inspection (pack disconnected, nothing powered)
- [ ] Case: no cracks, swelling, dents, heat marks, liquid, odour. Record photos (`PHOTOS_DIR`).
- [ ] Intake notes read (blinking blue / cut-wire / BMS anomalies?). Any anomaly → stop; a person judges it safe, or the pack is not tested.
- [ ] Connector/wire: XT60 present, pins undamaged, no melted housing, wire insulation intact. Record serial / label: ____________
- [ ] Pack LED/BMS status at rest recorded: ____________

## 3. Wiring check (power OFF, pack NOT connected, 6060B input OFF)
- [ ] Wiring matches `HARDWARE_FREEZE_CANDIDATE.md`: pack + → XT60 → fuse (15 A) → disconnect → relay → shunt (in series) → 6060B +; return to pack −.
- [ ] Disconnect (Blue Sea 6006) is **OFF**. Relay is de-energised (E-stop engaged, ARM off).
- [ ] Shunt sense (Kelvin) leads on the shunt's sense terminals, not on the power studs.
- [ ] Continuity with the EDU34450A: each joint low resistance, no short between + and −, relay contacts open (reading open) with the coil off.
- [ ] 6060B leads: correct polarity at the 6060B input terminals; wire gauge appropriate for the currents used (12 AWG in the BOM).
- [ ] EDU34450A voltage leads ready across the OSBAMS pack-voltage sense point (same point the INA228 bus input sees); current-mode leads NOT yet in circuit.

## 4. Polarity check
- [ ] With the EDU34450A in DC-voltage mode, touch the pack's XT60 contacts **before** mating: red lead on the contact expected to be +. Reading positive: ____ V. If negative or ambiguous → stop.
- [ ] Mate the pack to the OSBAMS XT60 **only** with the disconnect OFF and the relay open.

## 5. OCV measurement and profile selection (relay OPEN, no load) — steps C1–C4
- [ ] Close the Blue Sea disconnect (relay still open, 6060B input OFF). Confirm the dashboard shows pack voltage.
- [ ] **Relay-open verification:** relay not energised; PC9 feedback reads OFF; downstream of the relay reads ~0 V on the EDU34450A; current ≈ 0 A.
- [ ] Read OCV on the EDU34450A: ____ V. OSBAMS INA228: ____ V. ADC: ____ V. Record with `make_record('voltage', …)`.
- [ ] Sanity: OCV between 30.0 V (cutoff) and 42.5 V. At/below 30 V → pack deeply discharged: do not test, charge first. Above 43 V → stop, investigate.
- [ ] TC74 temperature: ____ °C vs EDU34450A ____ °C. TC74 not reading → the safety check will refuse to start (thermal protection unvalidated) — fix first.
- [ ] Select profile `ninebot_neb1002` in the dashboard. Read the limit panel: pack voltage, 6060B rating 60 A, power-derived limit, OSBAMS limit 10 A, profile limit 5.2 A, FINAL PERMITTED (expect 5.2 A at 42 V, 7.14 A is the instrument limit), limiting factor "battery profile". Matches the formula? ☐ yes ☐ no (stop)

## 6. 6060B setup (manual; remote control is blocked)
- [ ] Power the 6060B, run its self-test, record the settings (GPIB address, protection settings) — consult the 6060B Operating Manual for the exact front-panel procedure; do not guess keys.
- [ ] Input **OFF**. Mode **CC**. Current setpoint **0 A**. Leads connected only after the instrument is OFF.
- [ ] Confirm the setpoint you will use is ≤ FINAL PERMITTED (dashboard) **and** ≤ 0.5 A for the first load, ≤ 1.0 A for the profile run. Never enter a value because "the 6060B can do 60 A".
- [ ] Do not deliberately exceed 300 W on the instrument at any time.

## 7. First load — low current (steps D1, D2)
- [ ] EDU34450A: voltage across the pack at the sense point. For current comparison put it **in series** in current mode (check its current range/fuse and burden first) or skip the series current reading and rely on the 6060B readback + INA228 if the DMM burden is a concern; record which.
- [ ] EDUX1052G: probes on load-enable (PC8), relay downstream voltage, and the shunt/current signal; rated probes, good grounding, never an unrated probe on the pack path.
- [ ] Arm OSBAMS (ARM on, E-stop released), start the dashboard Capacity test; wait for READY (the hardware safety check must pass: registry status, temperature present and in limits, voltage envelope, positive permitted current, idle load).
- [ ] Confirm → relay closes → on the 6060B set **0.1 A**, input ON. Record OSBAMS I/V, 6060B readback, EDU34450A. Repeat at **0.25 A** and **0.5 A**, one minute each.
- [ ] Input OFF on the 6060B; verify measured current ≈ 0 (OSBAMS reports load-off confirmed).
- [ ] E-stop test at ≤ 0.5 A (D2): press E-stop while loaded; record fault-to-zero-current and E-stop-to-open on the scope; no unexpected transient. Re-arm only after verifying the pack and wiring.

## 8. Full test — orchestrated CC capacity (step E1)
Only if every earlier step passed with records saved.
- [ ] Dashboard Capacity test, profile `ninebot_neb1002`, requested current **1.0 A** (the profile's recommended value; the panel must show ≥ 1.0 A permitted).
- [ ] READY → confirm → on the 6060B CC **1.0 A**, input ON. Watch: current within 10 % of setpoint after 5 s; power ≈ V × 1 A (about 30–42 W); temperature rise.
- [ ] EDU34450A voltage spot checks at start, middle and end (record each with `make_record`).
- [ ] Do not leave the pack unattended. Re-read the pack temperature by hand at least every 30 minutes.
- [ ] Run ends automatically at the **30.0 V** profile cutoff → OSBAMS requests load OFF → **you** set the 6060B input OFF → OSBAMS confirms load-off from measured current → recovery rest (OSBAMS records recovery voltage at 30 s, 120 s, 300 s).
- [ ] Results saved: Ah, Wh, duration, min/end voltage, max temperature, initial sag, recovery voltages, SOH_capacity. Generate the report/passport.

## 9. Start conditions (all must hold)
Preconditions §1 satisfied · inspection, wiring and polarity checks done · OCV between 30.0 and 42.5 V · TC74 reading present and below 50 °C · relay-open verification done · FINAL PERMITTED ≥ setpoint · hardware safety check PASS · load input OFF and measured current ≈ 0 · operator + second person present.

## 10. Stop conditions
**Automatic (OSBAMS):** voltage ≤ 30.0 V on 3 consecutive samples (normal end); temperature ≥ 50 °C; voltage > 43 V; measured current more than 10 % (min 0.05 A) from the setpoint after 5 s, or above 115 % + 0.1 A of the commanded value; measured power > 300 W or `commanded × conservative V` > 300 W; no samples for 10 s; sensor/firmware fault flag; 8 h maximum; load current never appears after confirm (120 s); load-off not confirmed within 30 s → FAULT with an operator alert.
**Firmware (independent of the PC):** hard trip 18.5 A / 60 °C, E-stop, watchdog, host loss.
**Operator:** any smell, hissing, swelling, discolouration, unexpected heat at the pack, connector or relay, any unexplained reading, any doubt.

## 11. Emergency stop procedure
1. Press the **E-stop** (removes relay-coil power independently of the software).
2. Set the **6060B input OFF** at the front panel.
3. Confirm current ≈ 0 (dashboard and, if connected, the EDU34450A).
4. Only with current at zero, switch the **Blue Sea disconnect OFF** (it is not for routine switching under load).
5. If the pack is hot, swollen, smoking or venting: leave it where it is, move people away, do not touch it, and follow the laboratory's emergency procedure.
6. Record time, what was observed, and the dashboard state; do not retest until a person has reviewed the cause.

## 12. Data to record
| Item | Where |
|---|---|
| Operator, second person, date, software commit | calibration record header |
| Pack serial/label, photos, intake notes, polarity result | registry + this record |
| OCV (EDU34450A / INA228 / ADC), temperature (TC74 / reference) | calibration records (C1–C3) |
| Limit-panel values and limiting factor at start | screenshot |
| Low-current comparison table (OSBAMS / 6060B / EDU34450A) | calibration records (D1) |
| Scope captures: load-enable, E-stop, shutdown, transients | files named by step ID (B3, D1, D2) |
| Full run: readings, Ah, Wh, duration, cutoff, recovery, max temperature, SOH | database + report/passport (E1) |
| Anything unexpected | notes field of the acceptance record |

After the run: update `ValidationLog` with PASS/FAIL per step (needs operator and data location). Claim BENCH_TESTED only for what was actually measured.

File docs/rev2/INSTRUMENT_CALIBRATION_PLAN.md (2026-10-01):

# Instrument verification / calibration plan

Purpose: establish the **actual** error of each OSBAMS channel against the EDU34450A
before relying on any number. No tolerance is claimed anywhere until records exist.
Records: `equipment.reference.make_record` and the `calibration_records` table
(reference model, asset ID, calibration status, reference reading, OSBAMS reading,
absolute and percent error, timestamp, software commit, operator, optional 6060B readback).

| Quantity | OSBAMS channel | Reference | Where the points come from | Step |
|---|---|---|---|---|
| Pack voltage | INA228 bus | EDU34450A | pack OCV with the relay open; spot checks at start, mid and end of runs | C1, E1 |
| Pack voltage | independent ADC divider | EDU34450A (and the INA228) | same moment as C1; disagreement-fault threshold exercised by configuration | C2 |
| Current | INA228 / shunt | EDU34450A in series (current range/fuse checked first); 6060B panel readback | 0.1, 0.25, 0.5 A low-current run, then profile currents | D1, E1 |
| Power | INA228 | V × I from the references; 6060B readback | same points | D1, E1 |
| Resistance / continuity / polarity | wiring | EDU34450A | all power-path joints, power off | A2 |
| Temperature | TC74 | EDU34450A temperature function | ambient, then during runs | C3, E3 |

Procedure per point: settle, read the instruments together, `make_record(...)`,
`save_record(conn, rec)`. The acceptance tolerance is written beforehand by the operator.

Limitation: there is no swept source in the stack, so voltage is verified at the pack's
own operating points rather than over a 3–44 V sweep, and nothing is adjusted — the
result is a characterized error. Reference calibration status is read off the
EDU34450A (A1) and stays UNKNOWN until then. OSBAMS channel interval:
`config.CALIBRATION_INTERVAL_DAYS` (90).

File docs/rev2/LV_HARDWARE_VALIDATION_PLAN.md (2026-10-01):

# Rev.2 hardware validation plan (36–42 V lithium-ion packs)

Equipment: the 6060B (the actual battery load), the EDU34450A (reference
measurement) and the EDUX1052G (validation-only observation), plus the OSBAMS stack
itself — see `SFSU_EQUIPMENT_MATRIX.md`. Every step starts **NOT_RUN**; nothing is
BENCH_TESTED or HARDWARE_VALIDATED. The exact step list is `BENCH_CHECKLIST.md`
(generated from `desktop/equipment/validation.py`; track results with `ValidationLog`).

## The workflow
| Phase | Goal | Instruments | Steps |
|---|---|---|---|
| A | Record identities; inspect and record the power-path parts | EDU34450A | A1, A2 |
| B | Bench bring-up with **no battery**: sensors, frames, fault handling, relay coil-side timing | EDUX1052G | B1–B3 |
| C | Pack connected, **relay open, no load**: OCV verification, ADC cross-check, temperature, dashboard envelope check | EDU34450A | C1–C4 |
| D | First supervised **low-current** load (≤ 0.5 A): current comparison, E-stop/shutdown timing under load | 6060B (manual), EDU34450A, EDUX1052G | D1, D2 |
| E | Full characterization of the 36–42 V packs: capacity, DCIR, thermal, other packs, report/passport | 6060B (manual), EDU34450A | E1–E5 |
| F | Remote control — blocked (no confirmed GPIB path; no command VERIFIED) | — | F1–F4 |

## Rules for every step
- The operator writes the acceptance tolerance into the record **before** the run; no accuracy figure is claimed until then.
- A step is PASS only with an operator, recorded data and every prerequisite PASS (`ValidationLog`).
- The first loaded run (D1) is gated on every earlier non-optional step.
- Never deliberately exceed 300 W on the 6060B. The dashboard's FINAL PERMITTED value is the setpoint ceiling.
- Probe only with rated probes and good grounding; the scope's input rating is not permission to probe high-energy nodes.
- Packs with BMS anomalies in the intake notes are inspected and judged safe before any connection.

## Limits of this workflow (read before relying on it)
There is no variable bench source in the Rev.2 stack, so voltage and current are
**verified** against the EDU34450A at the pack's own operating points (OCV with the
relay open, then spot checks during low-current and full runs). The error of each
channel is characterized and recorded; it is not "calibrated" over a swept range.
Fault thresholds that would need an injected voltage are exercised only through
configuration (profile limits) and host/firmware tests.

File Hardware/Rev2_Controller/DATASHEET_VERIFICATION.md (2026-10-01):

# Evidence register (Rev.2 RC1)

Generated from `calc/datasheet_inputs.json`. States: **VERIFIED_LOCAL** (read by the build), **USER_RELAYED_MANUFACTURER** (manufacturer data supplied by the user; PDF not opened by the build), **UNVERIFIED** (assumption/proposal). Manufacturer sites are unreachable from the build environment (HTTP 403 policy denial), so nothing has been read from a manufacturer PDF by the build. Every `critical` entry must become VERIFIED_LOCAL (by you on your machine, or by a re-run that has the PDFs) before ordering.

| # | Item | Part | Parameter | Value | Evidence | Critical | Doc/location |
|---|---|---|---|---|---|---|---|
| 1 | `vo610a_ctr_min_1mA` | VO610A-1 | CTR min at IF=1 mA, VCE=5 V | 0.13 | USER_RELAYED_MANUFACTURER | **yes** | — |
| 2 | `vo610a_ctr_typ_1mA` | VO610A-1 | CTR typ at IF=1 mA, VCE=5 V | 0.3 | USER_RELAYED_MANUFACTURER | no | — |
| 3 | `vo610a_ctr_min_10mA` | VO610A-1 | CTR min at IF=10 mA, VCE=5 V | 0.4 | USER_RELAYED_MANUFACTURER | **yes** | — |
| 4 | `vo610a_ctr_max_10mA` | VO610A-1 | CTR max at IF=10 mA, VCE=5 V | 0.8 | USER_RELAYED_MANUFACTURER | no | — |
| 5 | `vo610a_ctr_monotonic` | VO610A-1 | CTR(IF) >= CTR(1 mA) for 1 mA <= IF <= 10 mA (curve is monotonic in this range) | assumed | UNVERIFIED | **yes** | — |
| 6 | `vo610a_temp_derate` | VO610A-1 | CTR derate over temperature (design margin, not a datasheet value) | 0.8 | UNVERIFIED | no | — |
| 7 | `vo610a_aging_derate` | VO610A-1 | CTR derate for aging (design margin, not a datasheet value) | 0.8 | UNVERIFIED | no | — |
| 8 | `vo610a_vf_max` | VO610A-1 | LED forward voltage max: 1.6 V at IF = 50 mA (used as a conservative bound at the low IF of this design; VF at 1-3 mA is lower) | 1.6 V | USER_RELAYED_MANUFACTURER | **yes** | — |
| 9 | `vo610a_vcesat` | VO610A-1 | VCE(sat) max at IC ~0.1 mA | 0.4 V | UNVERIFIED | no | — |
| 10 | `vo610a_vcesat_rel` | VO610A-1 | VCE(sat) max 0.3 V at IF = 10 mA, IC = 1 mA (design uses 0.4 V at IC ~ 0.07 mA as the conservative figure) | 0.3 V | USER_RELAYED_MANUFACTURER | no | — |
| 11 | `vo610a_ratings` | VO610A-1 | VCEO 70 V, IC max 50 mA, IF max 60 mA, operating -55..+110 C | — | USER_RELAYED_MANUFACTURER | no | — |
| 12 | `vo610a_led_vr` | VO610A-1 | LED reverse voltage absolute max | 6.0 V | USER_RELAYED_MANUFACTURER | no | — |
| 13 | `vo610a_pinout` | VO610A-1 | DIP-4 pinout: 1 LED anode, 2 LED cathode, 3 emitter, 4 collector | 1 A, 2 K, 3 E, 4 C | USER_RELAYED_MANUFACTURER | **yes** | — |
| 14 | `ina228_status` | INA228 | lifecycle / package | ACTIVE, VSSOP-10 | USER_RELAYED_MANUFACTURER | no | — |
| 15 | `ina228_supply` | INA228 | supply range | 2.7-5.5 V | VERIFIED_LOCAL | no | docs/rev2/pcb/evidence/TI_INA228_datasheet_SLYS021A_revA.pdf |
| 16 | `ina228_cm` | INA228 | Absolute Maximum Ratings (sec. 6.1): VIN+/VIN- common-mode -0.3 to 85 V; VBUS -0.3 to 85 V; VS 6 V; ALERT -0.3 to VS+0.3 V; SDA/SCL -0.3 to 6 V; input current into any pin 5 mA; HBM +/-2 kV, CDM +/-1 kV | -0.3 to +85 V | VERIFIED_LOCAL | **yes** | docs/rev2/pcb/evidence/TI_INA228_datasheet_SLYS021A_revA.pdf |
| 17 | `ina228_ranges` | INA228 | shunt full-scale ranges | +/-163.84 mV, +/-40.96 mV | VERIFIED_LOCAL | no | docs/rev2/pcb/evidence/TI_INA228_datasheet_SLYS021A_revA.pdf |
| 18 | `ina228_vos` | INA228 | shunt input offset max | 1e-06 V | VERIFIED_LOCAL | no | docs/rev2/pcb/evidence/TI_INA228_datasheet_SLYS021A_revA.pdf |
| 19 | `ina228_pinmap` | INA228 | DGS VSSOP-10 pin map (TI table; symbol compared pin-for-pin: PASS) | 1 A1, 2 A0, 3 ALERT, 4 SDA, 5 SCL, 6 VS, 7 GND, 8 VBUS, 9 IN-, 10 IN+ | VERIFIED_LOCAL | **yes** | docs/rev2/pcb/evidence/TI_INA228_datasheet_SLYS021A_revA.pdf |
| 20 | `ina228_shunt_cal` | INA228 | SHUNT_CAL = 13107.2e6 x CURRENT_LSB x RSHUNT (ADCRANGE 0); RSA-20-50, IMAX 20 A -> 1250 | 13107.2e6 x CURRENT_LSB x RSHUNT (x4 for ADCRANGE=1); max 32767 | VERIFIED_LOCAL | **yes** | docs/rev2/pcb/evidence/TI_INA228_datasheet_SLYS021A_revA.pdf |
| 21 | `ina228_bias` | INA228 | input bias current | 2.5e-09 A | VERIFIED_LOCAL | no | docs/rev2/pcb/evidence/TI_INA228_datasheet_SLYS021A_revA.pdf |
| 22 | `ina228_diff_max` | INA228 | Absolute Maximum Ratings (sec. 6.1): differential (VIN+) - (VIN-) = -40 V to +40 V. This is an absolute-maximum rating, separate from the +/-163.84 / +/-40.96 mV measurement ranges. Sec. 8.1: inputs tolerate +/-40 V differential; 10 ohm in series with each input protects against the dV/dt failure up to the 40 V differential rating; use RFILTER <= 100 ohm and CFILTER 0.1-1 uF | +/-40 V | VERIFIED_LOCAL | **yes** | docs/rev2/pcb/evidence/TI_INA228_datasheet_SLYS021A_revA.pdf |
| 23 | `lmr_status` | LMR14006Y | lifecycle / input / current | ACTIVE, 4-40 V, 0.6 A | USER_RELAYED_MANUFACTURER | no | — |
| 24 | `lmr_fsw` | LMR14006Y | switching frequency (Y suffix) | 2100000.0 Hz | USER_RELAYED_MANUFACTURER | no | — |
| 25 | `lmr_fsw_range` | LMR14006Y | switching frequency Y version: min 1.785 / typ 2.100 / max 2.415 MHz | — | USER_RELAYED_MANUFACTURER | no | — |
| 26 | `lmr_vref` | LMR14006Y | feedback reference | 0.765 V | USER_RELAYED_MANUFACTURER | **yes** | — |
| 27 | `lmr_vfb_range` | LMR14006Y | FB reference: min 0.747 / typ 0.765 / max 0.782 V | — | USER_RELAYED_MANUFACTURER | **yes** | — |
| 28 | `lmr_pkg` | LMR14006Y | package DDC (TSOT-6); KiCad SOT-23-6 (0.95 mm pitch) used - TI land pattern not compared | SOT-23-6 (DDC) | USER_RELAYED_MANUFACTURER | no | — |
| 29 | `lmr_pinmap` | LMR14006Y | DDC TSOT-6 pin map: 1 CB, 2 GND, 3 FB, 4 /SHDN, 5 VIN, 6 SW (symbol compared: PASS) | 1 CB, 2 GND, 3 FB, 4 /SHDN, 5 VIN, 6 SW | USER_RELAYED_MANUFACTURER | **yes** | — |
| 30 | `lmr_ton_min` | LMR14006Y | minimum turn-on time | 9.5e-08 s | USER_RELAYED_MANUFACTURER | **yes** | — |
| 31 | `lmr_limits` | LMR14006Y | VIN recommended 4-40 V, absolute max 45 V; IOUT 600 mA; current limit ~1.2 A typ; max duty (Y) ~97 % | — | USER_RELAYED_MANUFACTURER | no | — |
| 32 | `lmr_en` | LMR14006Y | EN threshold / abs max / pull-up method | — | UNVERIFIED | **yes** | — |
| 33 | `lmr_l_c` | LMR14006Y | Bourns SRN6045TA-100M: 10 uH +/-20 %, DCR 52 mohm, Irms 3.20 A, Isat 4.60 A (LMR14006Y current limit ~1.2 A typ is a separate [UR] entry) | Isat 4.6 A | VERIFIED_LOCAL | no | docs/rev2/pcb/evidence/SRN6045TA_datasheet.pdf |
| 34 | `dg57_basic` | DG57CM-5021-76-1012-R | SPST-NO, 12 V coil, ~1.6 W | as stated | USER_RELAYED_MANUFACTURER | no | — |
| 35 | `dg57_dc1` | DG57CM-5021-76-1012-R | DC1 rated load | 80 A @12 VDC, 60 A @36 VDC, 50 A @48 VDC | USER_RELAYED_MANUFACTURER | **yes** | — |
| 36 | `dg57_vmax` | DG57CM-5021-76-1012-R | maximum switching voltage | 145.0 VDC | USER_RELAYED_MANUFACTURER | no | — |
| 37 | `dg57_operate` | DG57CM-5021-76-1012-R | typical operate time | 0.007 s | USER_RELAYED_MANUFACTURER | no | — |
| 38 | `dg57_coil_ohm` | DG57CM-5021-76-1012-R | coil resistance 90 ohm +/-10 % at 23 C (code 1012) | 90.0 ohm | USER_RELAYED_MANUFACTURER | **yes** | — |
| 39 | `dg57_coil_l` | DG57CM-5021-76-1012-R | coil inductance / release time with diode | 0.2 H | UNVERIFIED | no | — |
| 40 | `dg57_pickup` | DG57CM-5021-76-1012-R | must-operate 7.2 V max @23 C; must-release 1.2 V min @23 C; max allowable coil 17.4 V @23 C / 12.5 V @85 C | 7.2 V | USER_RELAYED_MANUFACTURER | **yes** | — |
| 41 | `rsa_tol` | RSA-20-50 | tolerance | 0.0025 ratio | USER_RELAYED_MANUFACTURER | no | — |
| 42 | `rsa_tcr` | RSA-20-50 | element TCR | 1.5e-05 1/K | USER_RELAYED_MANUFACTURER | no | — |
| 43 | `rsa_derate` | RSA-20-50 | recommended continuous current <= 2/3 rated (13.3 A) | 13.3 A | USER_RELAYED_MANUFACTURER | no | — |
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

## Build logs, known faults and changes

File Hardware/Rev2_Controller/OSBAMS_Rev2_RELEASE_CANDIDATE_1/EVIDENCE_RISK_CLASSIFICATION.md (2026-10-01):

# Evidence risk classification — RC1.2e (2026-10-01)

Every register entry that is **not VERIFIED_LOCAL** is classified by what a wrong value could actually cause. `USER_RELAYED_MANUFACTURER` values are used as authoritative for electrical checks; the PDFs have not been read by the build. Entries read locally (ISO7721, CP2102N, SRN6045TA-100M, EB21A drawing, KiCad library facts) are not listed.

59 entries are not VERIFIED_LOCAL: WRONG_PINOUT: 4, EXCEEDED_ABS_MAX: 12, WRONG_FOOTPRINT: 5, UNSAFE_PROTECTION: 4, FIRST_ARTICLE / INFORMATIONAL: 34.

## Could cause a WRONG PINOUT (supply the datasheet to move these to VERIFIED_LOCAL — highest priority)

| id | part | parameter | evidence | note |
|---|---|---|---|---|
| `vo610a_pinout` | VO610A-1 | DIP-4 pinout: 1 LED anode, 2 LED cathode, 3 emitter, 4 collector | USER_RELAYED_MANUFACTURER | DIP-4 opto: wrong pin order would make both status inputs dead; relayed pinout matches the netlist. |
| `lmr_pinmap` | LMR14006Y | DDC TSOT-6 pin map: 1 CB, 2 GND, 3 FB, 4 /SHDN, 5 VIN, 6 SW (symbol compared: PASS) | USER_RELAYED_MANUFACTURER | relayed table matches; a mismatch would stop the 3.3 V rail. |
| `q_pinout` | IRLML0060TRPBF | SOT-23 (Micro3) pinout 1 G, 2 S, 3 D (netlist compared: PASS) | USER_RELAYED_MANUFACTURER | relayed 1 G / 2 S / 3 D matches; a mismatch would leave the relay always off/on. |
| `tc74_pinmap` | TC74A5-3.3VAT | TO-220-5 pin map: 1 NC, 2 SDA, 3 GND, 4 SCLK, 5 VDD; tab = pin 3 (GND); supply 2.7-5.5 V; +/-2 C (25-85 C); sy | USER_RELAYED_MANUFACTURER | relayed table matches (probe board). |

## Could cause an EXCEEDED ABSOLUTE MAXIMUM

| id | part | parameter | evidence | note |
|---|---|---|---|---|
| `vo610a_ratings` | VO610A-1 | VCEO 70 V, IC max 50 mA, IF max 60 mA, operating -55..+110 C | USER_RELAYED_MANUFACTURER | VCEO 70 V vs the 3.3 V pull-up: large margin. |
| `vo610a_led_vr` | VO610A-1 | LED reverse voltage absolute max | USER_RELAYED_MANUFACTURER | 1N4148 limits the LED reverse voltage to ~0.7 V. |
| `lmr_limits` | LMR14006Y | VIN recommended 4-40 V, absolute max 45 V; IOUT 600 mA; current limit ~1.2 A typ; max duty (Y) ~97 % | USER_RELAYED_MANUFACTURER | VIN abs max 45 V vs SMBJ15A clamp 24.4 V (relayed). |
| `lmr_en` | LMR14006Y | EN threshold / abs max / pull-up method | UNVERIFIED | SHDN threshold/abs max not relayed; SHDN is pulled to +12V through 100 k (limits current); confirm the pin allows +12 V through 100 k. |
| `dg57_vmax` | DG57CM-5021-76-1012-R | maximum switching voltage | USER_RELAYED_MANUFACTURER | 145 VDC switching vs 44 V ceiling. |
| `dg57_pickup` | DG57CM-5021-76-1012-R | must-operate 7.2 V max @23 C; must-release 1.2 V min @23 C; max allowable coil 17.4 V @23 C / 12.5 V @85 C | USER_RELAYED_MANUFACTURER | coil max allowable 12.5 V at 85 C vs the XDR set to 12.0 V: needs the XDR set/verified at 12.0 V (first article). |
| `tvs15` | SMBJ15A | clamp 24.4 V in series table | USER_RELAYED_MANUFACTURER | SMBJ15A clamp vs LMR14006 VIN abs max 45 V (relayed). |
| `stm32_io` | STM32L476RGT6 | PA1 (pin 15) FT_la, ADC12_IN6 - NOT 5 V tolerant while the analog switch is connected (diode to VDDA/VREF+); P | USER_RELAYED_MANUFACTURER | PA1 not 5 V tolerant while the ADC switch is connected: the clamp network protects it (relayed structure). |
| `stm32_vrefint_range` | STM32L476RGT6 | VREFINT typ 1.212 V, 1.182-1.232 V over temperature; per-device factory calibration constant in system memory | USER_RELAYED_MANUFACTURER | firmware must use the factory calibration constant. |
| `q_vdss` | IRLML0060TRPBF | VDSS | USER_RELAYED_MANUFACTURER | 60 V vs 12 V coil + flyback: large margin. |
| `bat54s_ir` | BAT54S | reverse leakage at ~3 V | UNVERIFIED | diode leakage/forward voltage enter the PA1 back-feed analysis; the R4 bleeder guards the unknown. |
| `bat54s_vf` | BAT54S | forward voltage at 0.1 mA | UNVERIFIED | same. |

## Could cause a WRONG FOOTPRINT

| id | part | parameter | evidence | note |
|---|---|---|---|---|
| `lmr_pkg` | LMR14006Y | package DDC (TSOT-6); KiCad SOT-23-6 (0.95 mm pitch) used - TI land pattern not compared | USER_RELAYED_MANUFACTURER | KiCad SOT-23-6 vs the TI DDC land pattern (pitch/pin numbering match; land pattern not compared). |
| `conn_pitch` | Molex 22-27-2031/2041, JST B4B-PH-K-S, Samtec FTSH-105-01-L-DV-K, GCT USB4105-GF-A | pitch/pin count vs KiCad stock footprints: KK 2.54 mm x3/x4, PH 2.00 mm x4 (A = 6.0 mm), FTSH 1.27 mm 2x5, USB | USER_RELAYED_MANUFACTURER | pitch and pin count match. |
| `conn_samtec_key` | Samtec FTSH-105-01-L-DV-K (J9) | Samtec -K keying: which long side of the shroud carries the key slot (pin-1 row side vs pin-2 row side) is not | UNVERIFIED | J9 land pattern is verified; which shroud side carries the -K key slot is not resolved by the drawings -> check on the part (F6). |
| `conn_molex` | Molex 22-27-2031 / 22-27-2041 (J5, J6) | J5/J6 PCB hole and pad (drill 1.19, pad 1.74 x 2.19): NOT in the supplied Molex 3D models, product pages or pr | UNVERIFIED | J5/J6 mechanical geometry verified from the Molex 3D model; hole/pad = KiCad library values (not in the supplied Molex files) -> F7. |
| `conn_footprints` | Molex KK/JST PH/GCT USB4105/Samtec FTSH | connector footprints: J7 (JST) and J8 (GCT) VERIFIED against the drawings; J9 (Samtec) part number/pitch/tail  | UNVERIFIED | J7, J8 and J9 verified against manufacturer drawings; J5/J6 (Molex) still OPEN. |

## Protection-related (analysis closed in `REV2_CALCULATIONS.md` using the relayed numbers)

| id | part | parameter | evidence | note |
|---|---|---|---|---|
| `ina228_status` | INA228 | lifecycle / package | USER_RELAYED_MANUFACTURER | informational. |
| `dg57_dc1` | DG57CM-5021-76-1012-R | DC1 rated load | USER_RELAYED_MANUFACTURER | relay DC rating >> the 10 A / 44 V ceiling. |
| `rs_pulse_rating` | Panasonic ERJ-P08F47R0V / ERJ-P08F10R0V | ERJP08 single-pulse / repetitive-pulse capability: NOT PUBLISHED. AOA0000C331 (read) gives ratings (0.66 W, 50 | UNVERIFIED | Not published: AOA0000C331 and the catalog (both read) give DC ratings and the +/-3 kV 150 pF ESD test only. ERJP08 catalog row (read locally): 500 V limiting / 1000 V overload (a relayed 125/500 V does not match; 125 is the terminal temperature in C); modeled 8 kV ESD = about 1.3 kV across R41, above the 1000 V overload rating -> ESD_PROTECTION_OPEN. |
| `esd_connector` | J5/J6 connectors | ESD_FIRST_ARTICLE_CONDITIONAL (RC-A = YES confirmed: J5/J6 internal, permanently mated; reopen and require the | UNVERIFIED | ESD at J5/J6 cannot be shown by simulation; R41-R43 sit upstream of the TVS -> first-article test F1, connector-level TVS = RC1.3 fallback. |

## First-article measurements / design margins / informational (cannot cause a wrong pinout, absolute-maximum violation, wrong footprint or unsafe protection)

| id | part | parameter | evidence | note |
|---|---|---|---|---|
| `vo610a_ctr_min_1mA` | VO610A-1 | CTR min at IF=1 mA, VCE=5 V | USER_RELAYED_MANUFACTURER |  |
| `vo610a_ctr_typ_1mA` | VO610A-1 | CTR typ at IF=1 mA, VCE=5 V | USER_RELAYED_MANUFACTURER |  |
| `vo610a_ctr_min_10mA` | VO610A-1 | CTR min at IF=10 mA, VCE=5 V | USER_RELAYED_MANUFACTURER |  |
| `vo610a_ctr_max_10mA` | VO610A-1 | CTR max at IF=10 mA, VCE=5 V | USER_RELAYED_MANUFACTURER |  |
| `vo610a_ctr_monotonic` | VO610A-1 | CTR(IF) >= CTR(1 mA) for 1 mA <= IF <= 10 mA (curve is monotonic in this range) | UNVERIFIED |  |
| `vo610a_temp_derate` | VO610A-1 | CTR derate over temperature (design margin, not a datasheet value) | UNVERIFIED |  |
| `vo610a_aging_derate` | VO610A-1 | CTR derate for aging (design margin, not a datasheet value) | UNVERIFIED |  |
| `vo610a_vf_max` | VO610A-1 | LED forward voltage max: 1.6 V at IF = 50 mA (used as a conservative bound at the low IF of this design; VF at | USER_RELAYED_MANUFACTURER |  |
| `vo610a_vcesat` | VO610A-1 | VCE(sat) max at IC ~0.1 mA | UNVERIFIED |  |
| `vo610a_vcesat_rel` | VO610A-1 | VCE(sat) max 0.3 V at IF = 10 mA, IC = 1 mA (design uses 0.4 V at IC ~ 0.07 mA as the conservative figure) | USER_RELAYED_MANUFACTURER |  |
| `lmr_status` | LMR14006Y | lifecycle / input / current | USER_RELAYED_MANUFACTURER |  |
| `lmr_fsw` | LMR14006Y | switching frequency (Y suffix) | USER_RELAYED_MANUFACTURER |  |
| `lmr_fsw_range` | LMR14006Y | switching frequency Y version: min 1.785 / typ 2.100 / max 2.415 MHz | USER_RELAYED_MANUFACTURER |  |
| `lmr_vref` | LMR14006Y | feedback reference | USER_RELAYED_MANUFACTURER |  |
| `lmr_vfb_range` | LMR14006Y | FB reference: min 0.747 / typ 0.765 / max 0.782 V | USER_RELAYED_MANUFACTURER |  |
| `lmr_ton_min` | LMR14006Y | minimum turn-on time | USER_RELAYED_MANUFACTURER |  |
| `dg57_basic` | DG57CM-5021-76-1012-R | SPST-NO, 12 V coil, ~1.6 W | USER_RELAYED_MANUFACTURER |  |
| `dg57_operate` | DG57CM-5021-76-1012-R | typical operate time | USER_RELAYED_MANUFACTURER |  |
| `dg57_coil_ohm` | DG57CM-5021-76-1012-R | coil resistance 90 ohm +/-10 % at 23 C (code 1012) | USER_RELAYED_MANUFACTURER |  |
| `dg57_coil_l` | DG57CM-5021-76-1012-R | coil inductance / release time with diode | UNVERIFIED |  |
| `rsa_tol` | RSA-20-50 | tolerance | USER_RELAYED_MANUFACTURER |  |
| `rsa_tcr` | RSA-20-50 | element TCR | USER_RELAYED_MANUFACTURER |  |
| `rsa_derate` | RSA-20-50 | recommended continuous current <= 2/3 rated (13.3 A) | USER_RELAYED_MANUFACTURER |  |
| `tvs_leakage_temp` | 1.5SMBJ48A | reverse leakage vs temperature and vs voltage below VRWM: NOT specified in the datasheet (only the 25 C maximu | UNVERIFIED | Bourns gives IR <= 1.0 uA at 48 V/25 C only; leakage vs temperature/voltage is unspecified: sets the hot Kelvin-line offset (4 mA per uA) and the PACK_INA error (47 uV per uA) -> first-article measurement. |
| `iso_basic` | ISO7721 | 1 fwd + 1 rev channel, no integrated isolated power | USER_RELAYED_MANUFACTURER |  |
| `stm32_vih` | STM32L476RGT6 | VIH min as fraction of VDD | UNVERIFIED |  |
| `stm32_vih_ttl` | STM32L476RGT6 | TTL input levels: VIH min 2.0 V, VIL max 0.8 V; CMOS VIL max 0.3 VDD (CMOS VIH min not relayed) | USER_RELAYED_MANUFACTURER |  |
| `stm32_vrefint` | STM32L476RGT6 | VREFINT calibration accuracy | UNVERIFIED |  |
| `stm32_por` | STM32L476RGT6 | power-on reset release threshold (min) | UNVERIFIED |  |
| `stm32_tue` | STM32L476RGT6 | ADC total unadjusted error (LSB) | UNVERIFIED |  |
| `q_vth` | IRLML0060TRPBF | VGS(th) 1.0-2.5 V (max used) | USER_RELAYED_MANUFACTURER |  |
| `q_rds` | IRLML0060TRPBF | RDS(on) at VGS = 3.3 V (not specified: conservative placeholder) | UNVERIFIED |  |
| `q_rds_4v5` | IRLML0060TRPBF | RDS(on) max 116 mohm @ VGS 4.5 V, 92 mohm @ 10 V; ID 2.7 A @10 V; VGS +/-16 V; RthJA ~100 C/W (NOT guaranteed  | USER_RELAYED_MANUFACTURER |  |
| `q_curves` | IRLML0060TRPBF | Infineon typical output curves at VGS 3.0 and 3.3 V make the ~0.17 A coil load plausible; RDS(on) is NOT guara | USER_RELAYED_MANUFACTURER |  |

## Mandatory first-article measurements (not PCBWay blockers)
1. **Relay driver (IRLML0060, K1 coil):** VGS at the gate, VDS while energized, coil current (expect ≈ 121–148 mA at 12.0 V), MOSFET case temperature; XDR output set and verified at 12.0 V (coil limit 12.5 V at 85 °C).
2. **3V3 / 3V3_A:** ripple and level with the real load, and during an input step to 12.5 V; confirm no pulse-skipping instability at 12.0 V.
3. **INA228 chain:** shunt voltage at 0 A (leakage of the TVS diodes through R42/R43, cold and warm), VBUS vs the EDU34450A, scope on IN+/IN− during sense-harness hot-plug.
4. **PA1 ADC protection:** pack powered / controller unpowered, reversed pack, injection test; read VREFINT calibration.
5. **Status networks:** ESTOP_SENSE and RELAY_FB thresholds at 10.5–15 V and 24–44 V; ARM_SENSE.
6. **CP2102N / ISO7721:** USB enumeration, VBUS detect (reference divider: threshold 3.96 V typical, 4.40 V worst case), UART echo through the isolator, 3V3_HOST rail current.

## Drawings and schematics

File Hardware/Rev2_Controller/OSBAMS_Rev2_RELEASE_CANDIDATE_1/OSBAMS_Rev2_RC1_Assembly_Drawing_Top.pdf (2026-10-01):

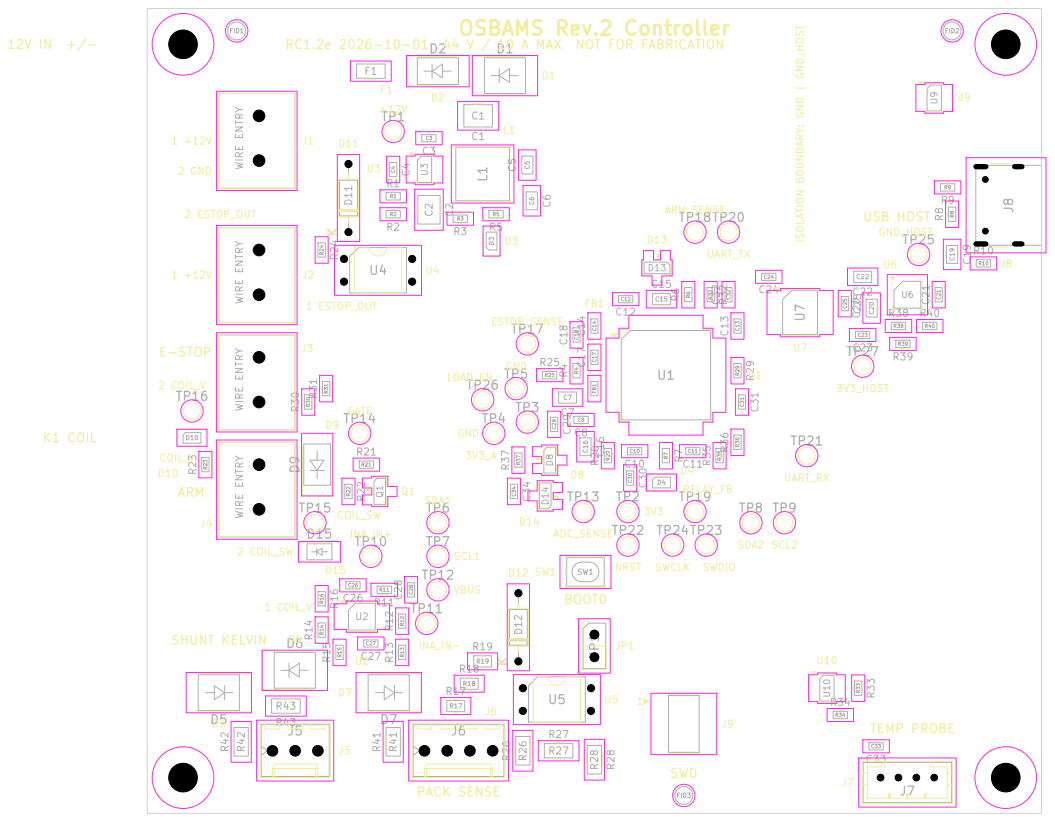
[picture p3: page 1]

TEMP PROBE K1 COIL 12V IN +/-

RC1.2e 2026-10-01 44 V / 10 A MAX NOT FOR FABRICATION

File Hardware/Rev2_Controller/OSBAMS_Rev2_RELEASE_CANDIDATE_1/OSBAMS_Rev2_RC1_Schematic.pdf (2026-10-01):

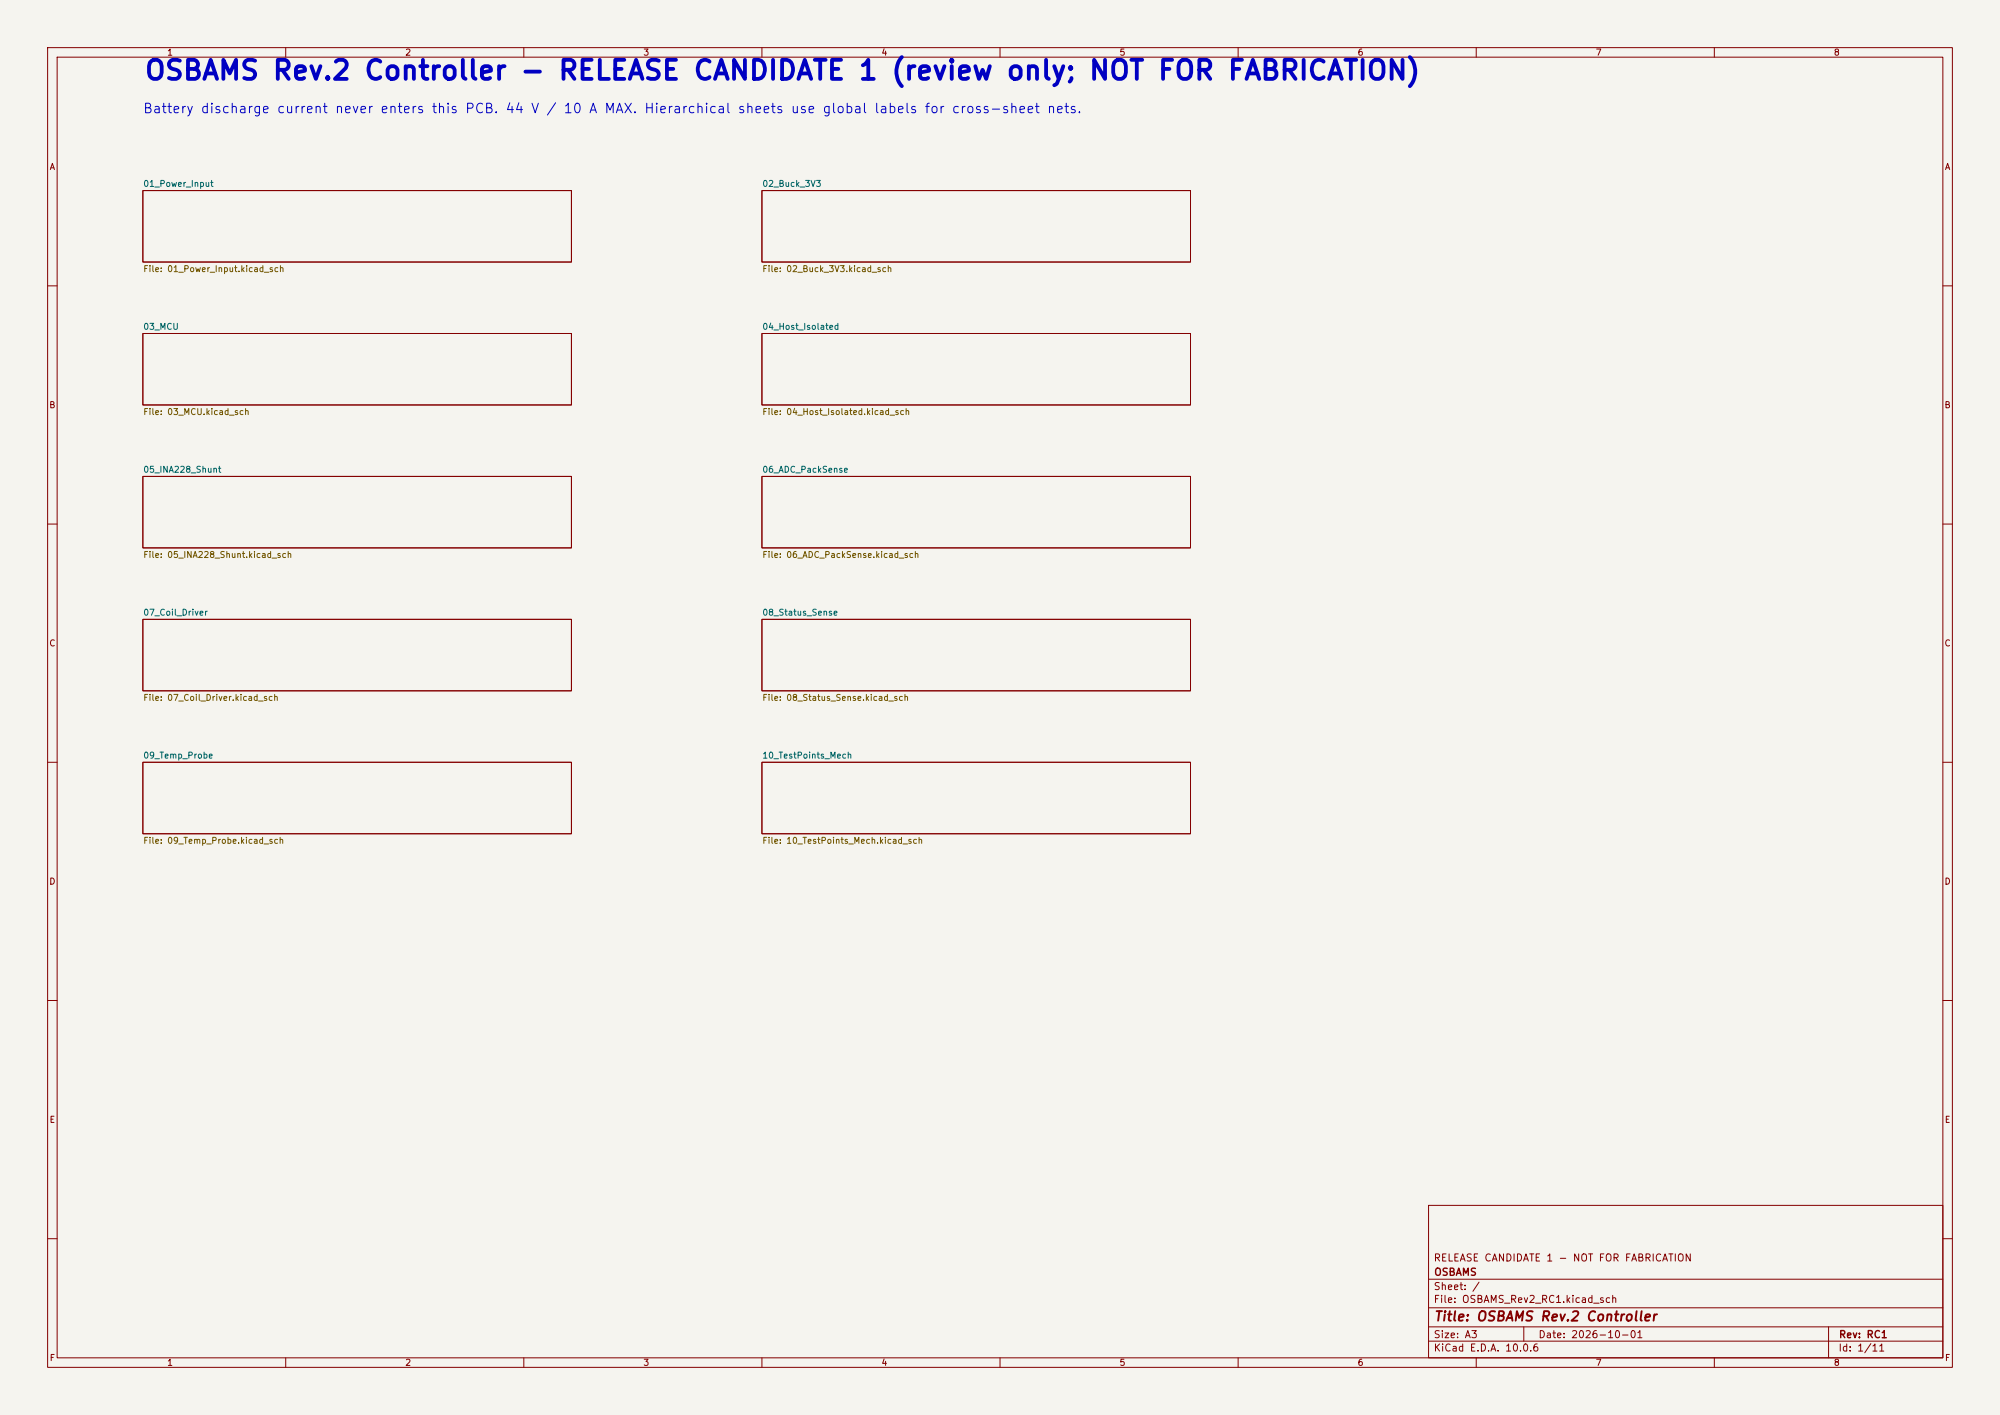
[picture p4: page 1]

File: 10_TestPoints_Mech.kicad_sch OSBAMS Rev.2 Controller - RELEASE CANDIDATE 1 (review only; NOT FOR FABRICATION)

Battery discharge current never enters this PCB. 44 V / 10 A MAX. Hierarchical sheets use global labels for cross-sheet nets.

RELEASE CANDIDATE 1 - NOT FOR FABRICATION
OSBAMS
Sheet: /
File: OSBAMS_Rev2_RC1.kicad_sch
Title: OSBAMS Rev.2 Controller

Size: A3 | Rev: RC1 | F Date: 2026-10-01
KiCad E.D.A. 10.0.6 | Id: 1/11

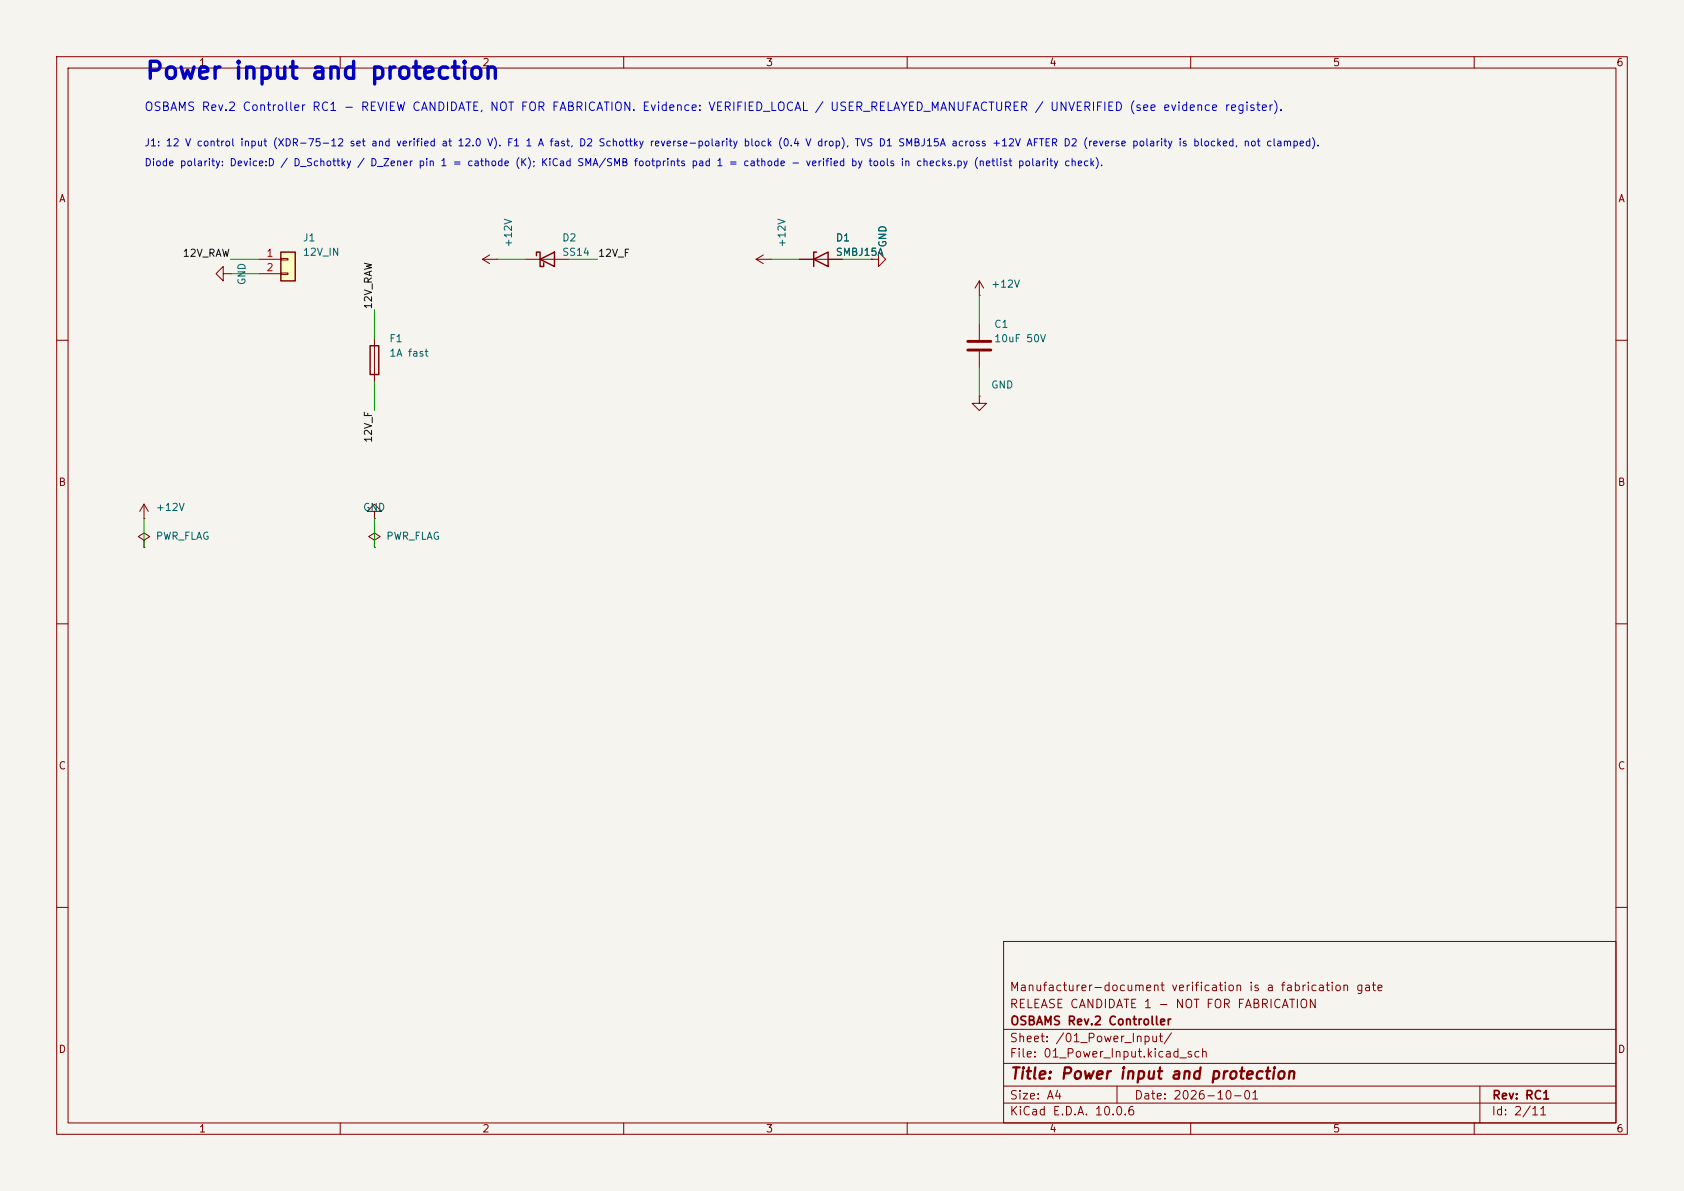
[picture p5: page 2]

Power input and protection

OSBAMS Rev.2 Controller RC1 - REVIEW CANDIDATE, NOT FOR FABRICATION. Evidence: VERIFIED_LOCAL / USER_RELAYED_MANUFACTURER / UNVERIFIED (see evidence register). Diode polarity: Device:D / D_Schottky / D_Zener pin 1 = cathode (K); KiCad SMA/SMB footprints pad 1 = cathode - verified by tools in checks.py (netlist polarity check). GND D1

J1: 12 V control input (XDR-75-12 set and verified at 12.0 V). F1 1 A fast, D2 Schottky reverse-polarity block (0.4 V drop), TVS D1 SMBJ15A across +12V AFTER D2 (reverse polarity is blocked, not clamped).

Manufacturer-document verification is a fabrication gate
RELEASE CANDIDATE 1 - NOT FOR FABRICATION
OSBAMS Rev.2 Controller
Sheet: /01_Power_Input/
File: 01_Power_Input.kicad_sch
Title: Power input and protection

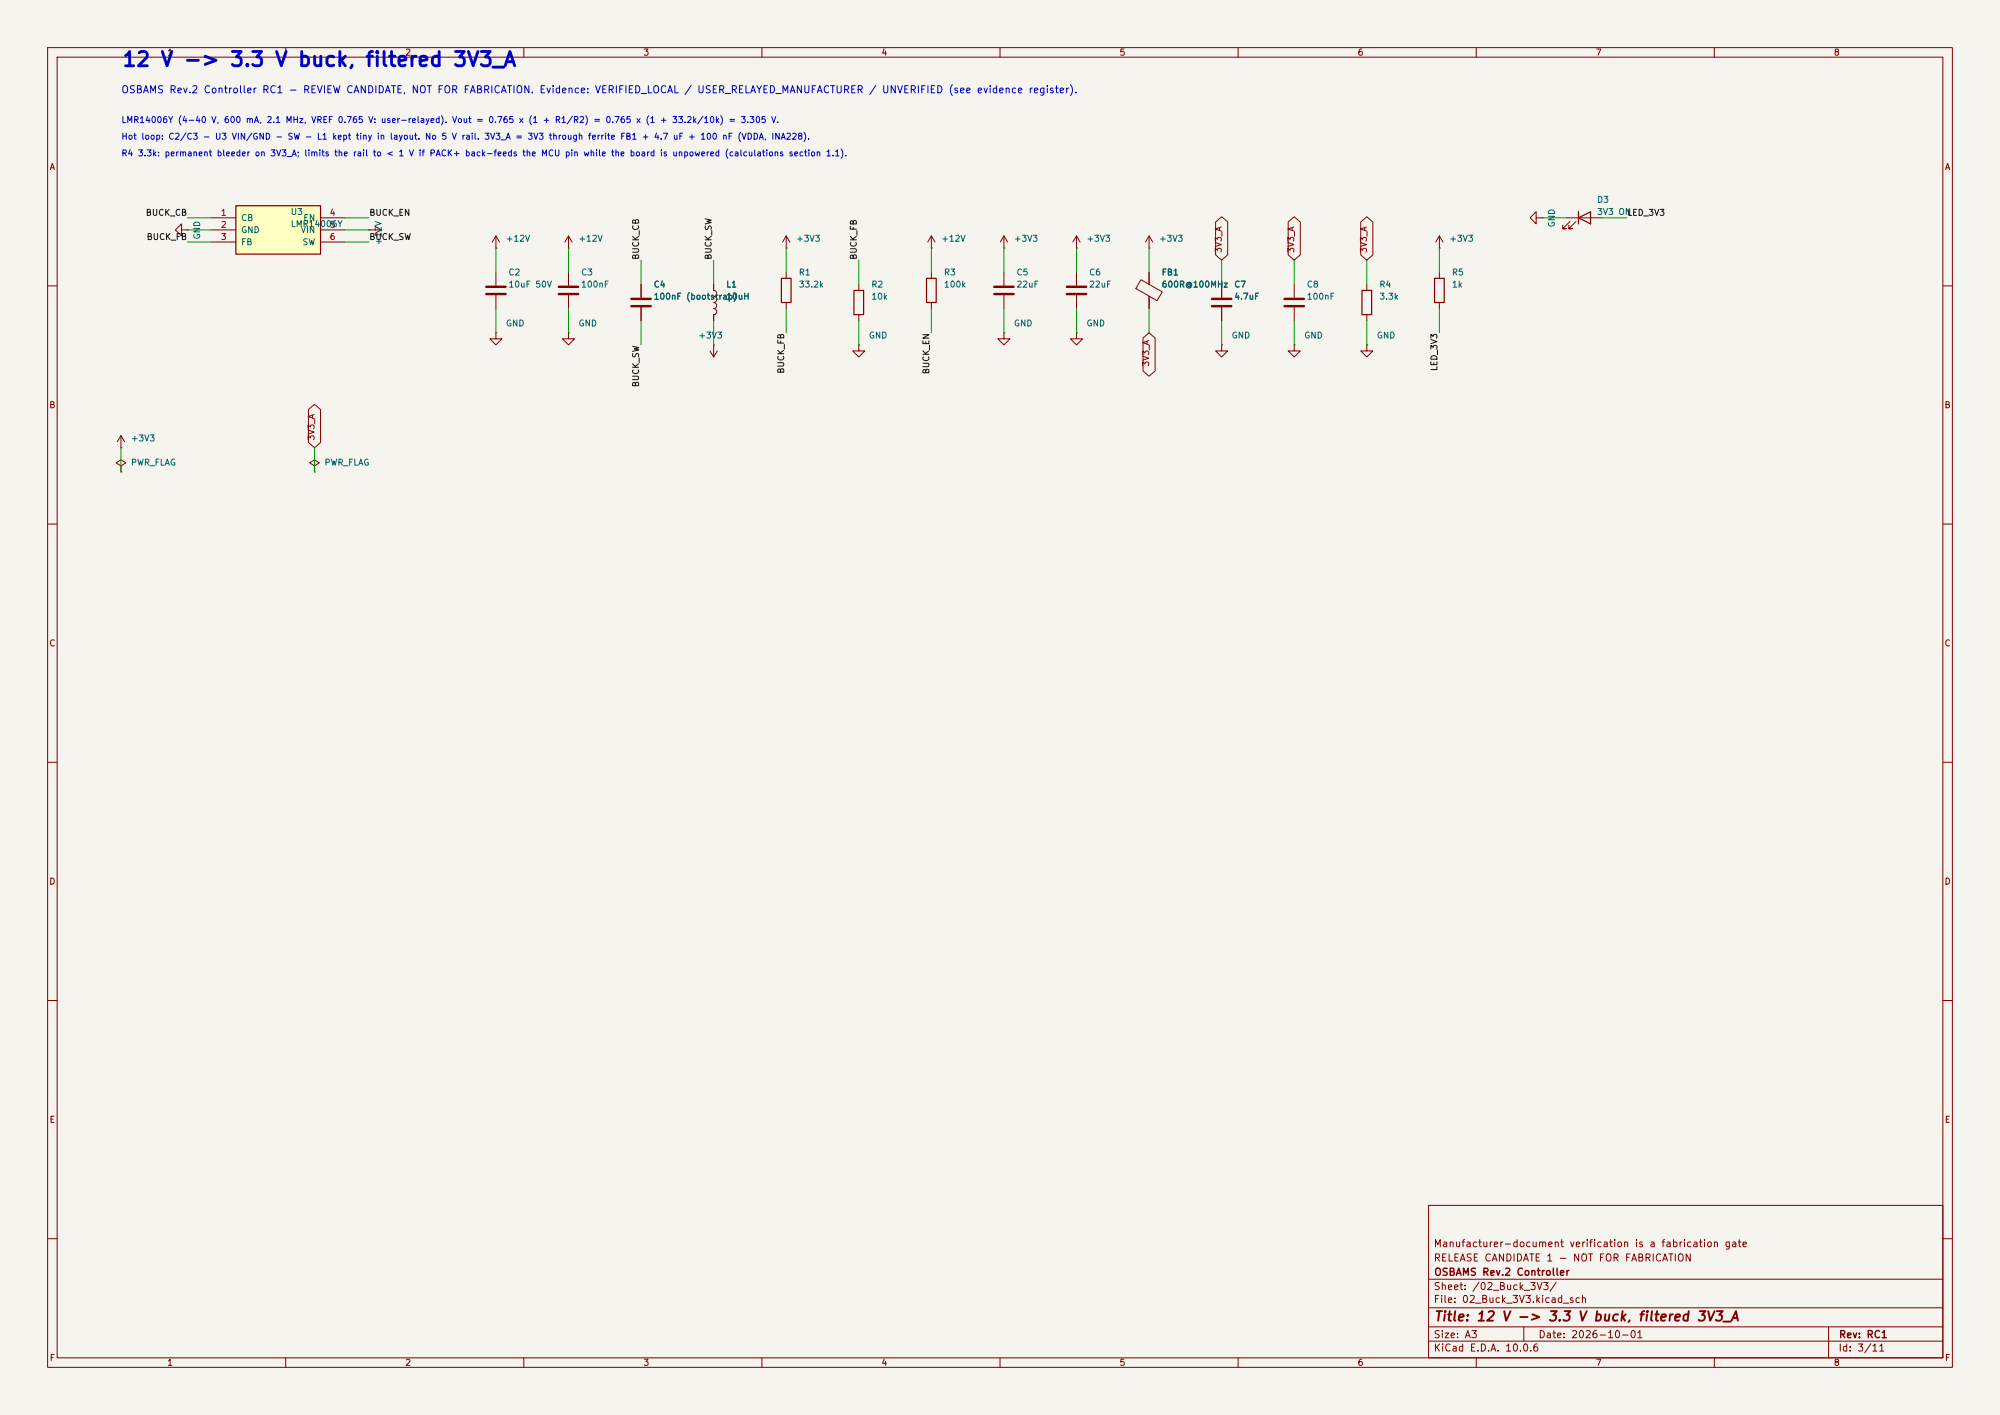
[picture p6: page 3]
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

LMR14006Y (4-40 V, 600 mA, 2.1 MHz, VREF 0.765 V: user-relayed). Vout = 0.765 x (1 + R1/R2) = 0.765 x (1 + 33.2k/10k) = 3.305 V. Hot loop: C2/C3 - U3 VIN/GND - SW - L1 kept tiny in layout. No 5 V rail. 3V3_A = 3V3 through ferrite FB1 + 4.7 uF + 100 nF (VDDA, INA228). R4 3.3k: permanent bleeder on 3V3_A; limits the rail to < 1 V if PACK+ back-feeds the MCU pin while the board is unpowered (calculations section 1.1).

Manufacturer-document verification is a fabrication gate
RELEASE CANDIDATE 1 - NOT FOR FABRICATION
OSBAMS Rev.2 Controller
Sheet: /02_Buck_3V3/
File: 02_Buck_3V3.kicad_sch
Title: 12 V -> 3.3 V buck, filtered 3V3_A

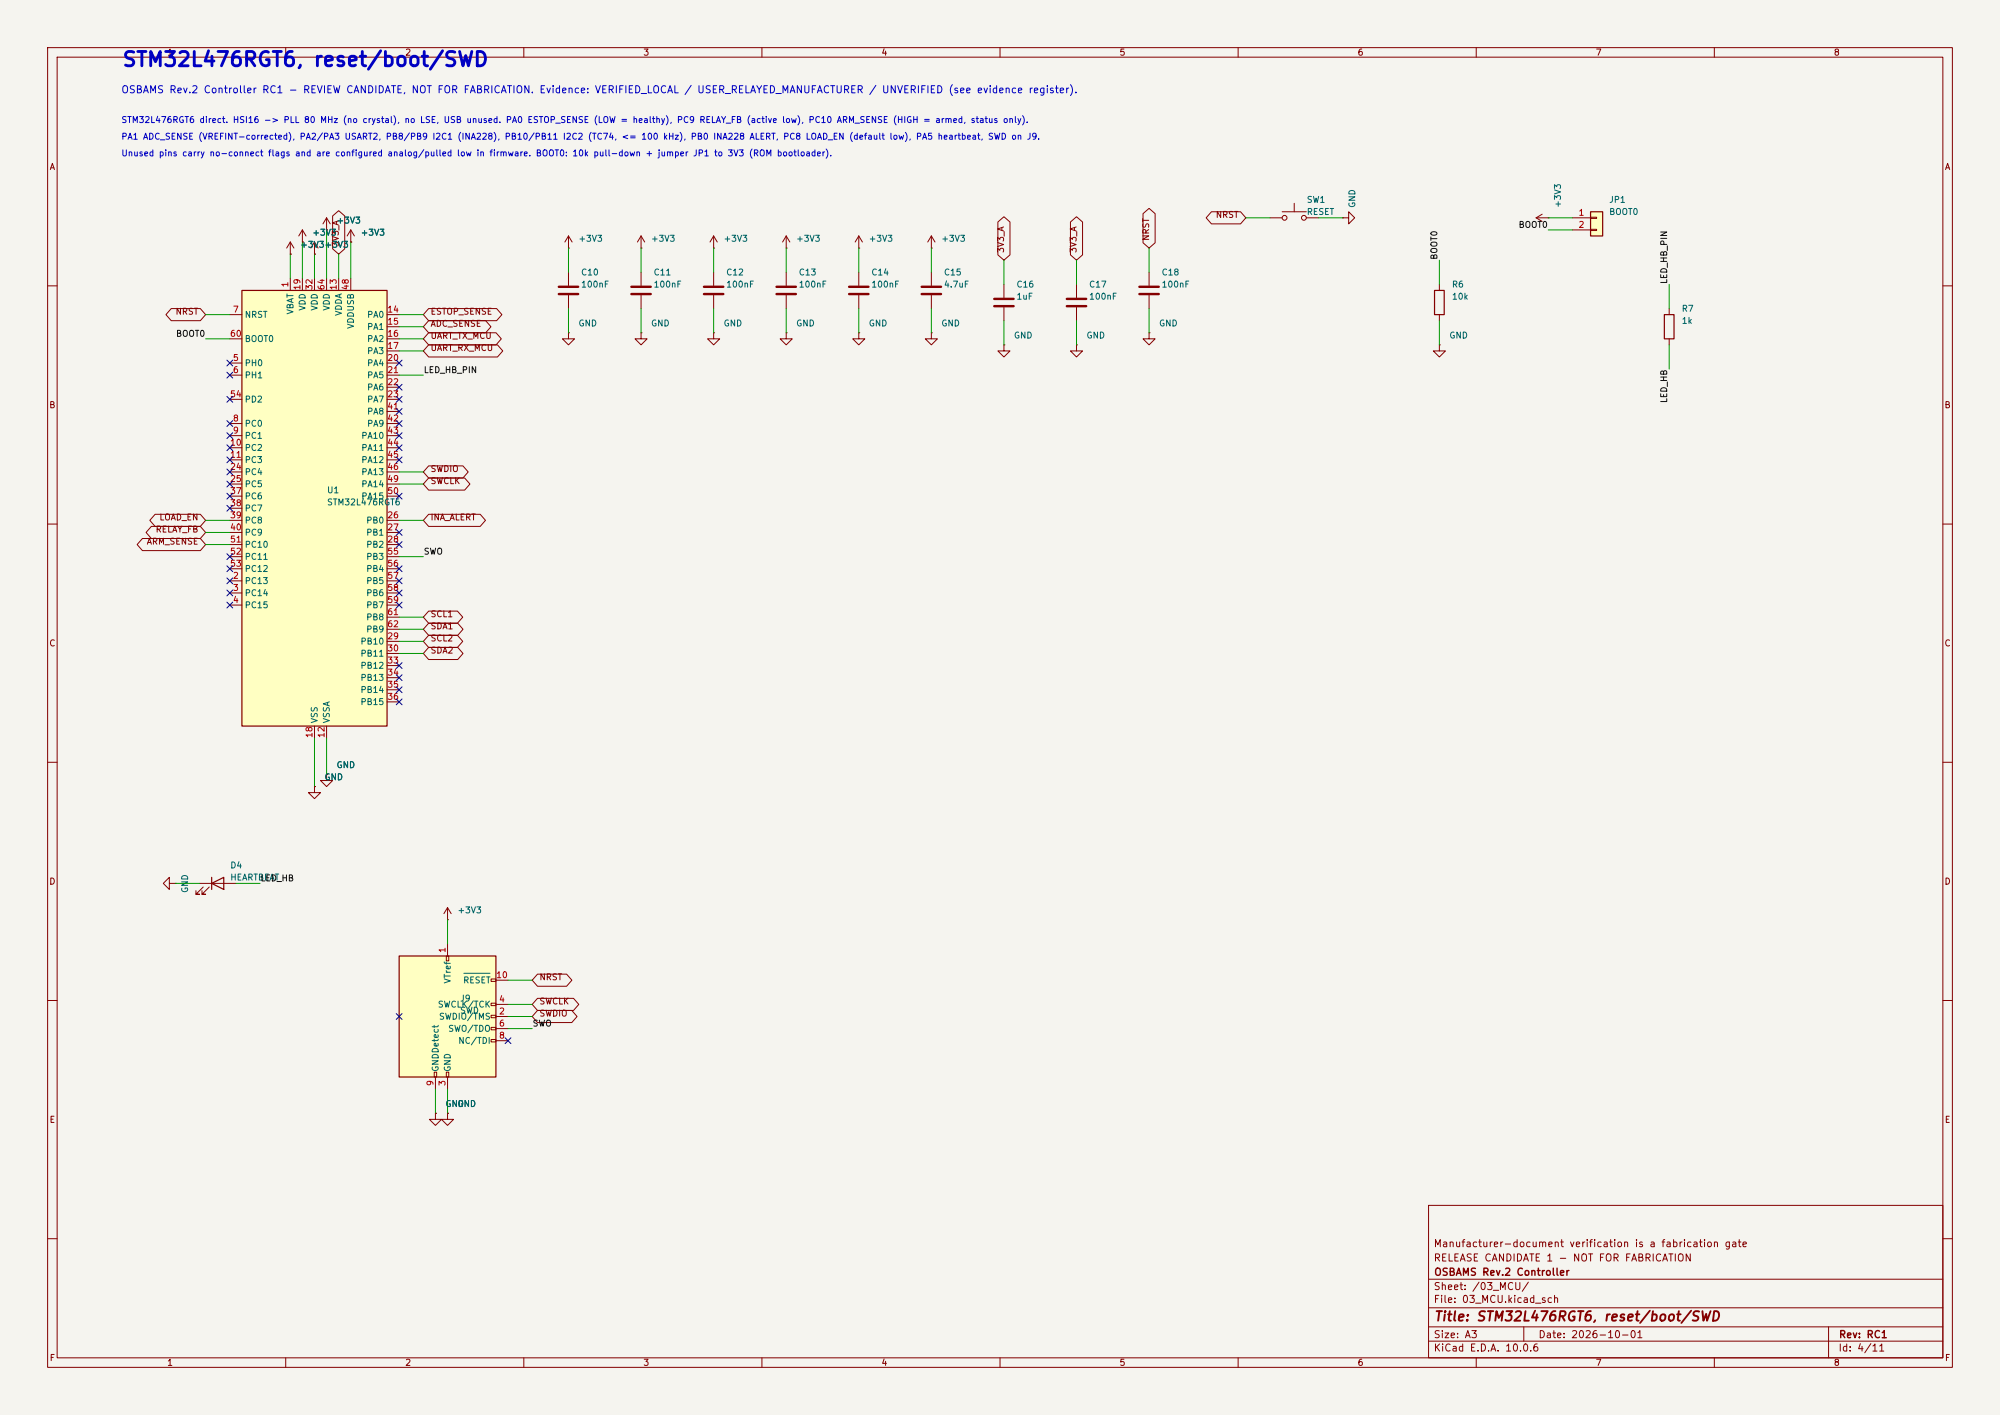
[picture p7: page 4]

STM32L476RGT6 direct. HSI16 -> PLL 80 MHz (no crystal), no LSE, USB unused. PA0 ESTOP_SENSE (LOW = healthy), PC9 RELAY_FB (active low), PC10 ARM_SENSE (HIGH = armed, status only). PA1 ADC_SENSE (VREFINT-corrected), PA2/PA3 USART2, PB8/PB9 I2C1 (INA228), PB10/PB11 I2C2 (TC74, <= 100 kHz), PB0 INA228 ALERT, PC8 LOAD_EN (default low), PA5 heartbeat, SWD on J9. STM32L476RGT6, reset/boot/SWD

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

Unused pins carry no-connect flags and are configured analog/pulled low in firmware. BOOT0: 10k pull-down + jumper JP1 to 3V3 (ROM bootloader).

Manufacturer-document verification is a fabrication gate
RELEASE CANDIDATE 1 - NOT FOR FABRICATION
OSBAMS Rev.2 Controller
Sheet: /03_MCU/
File: 03_MCU.kicad_sch
Title: STM32L476RGT6, reset/boot/SWD

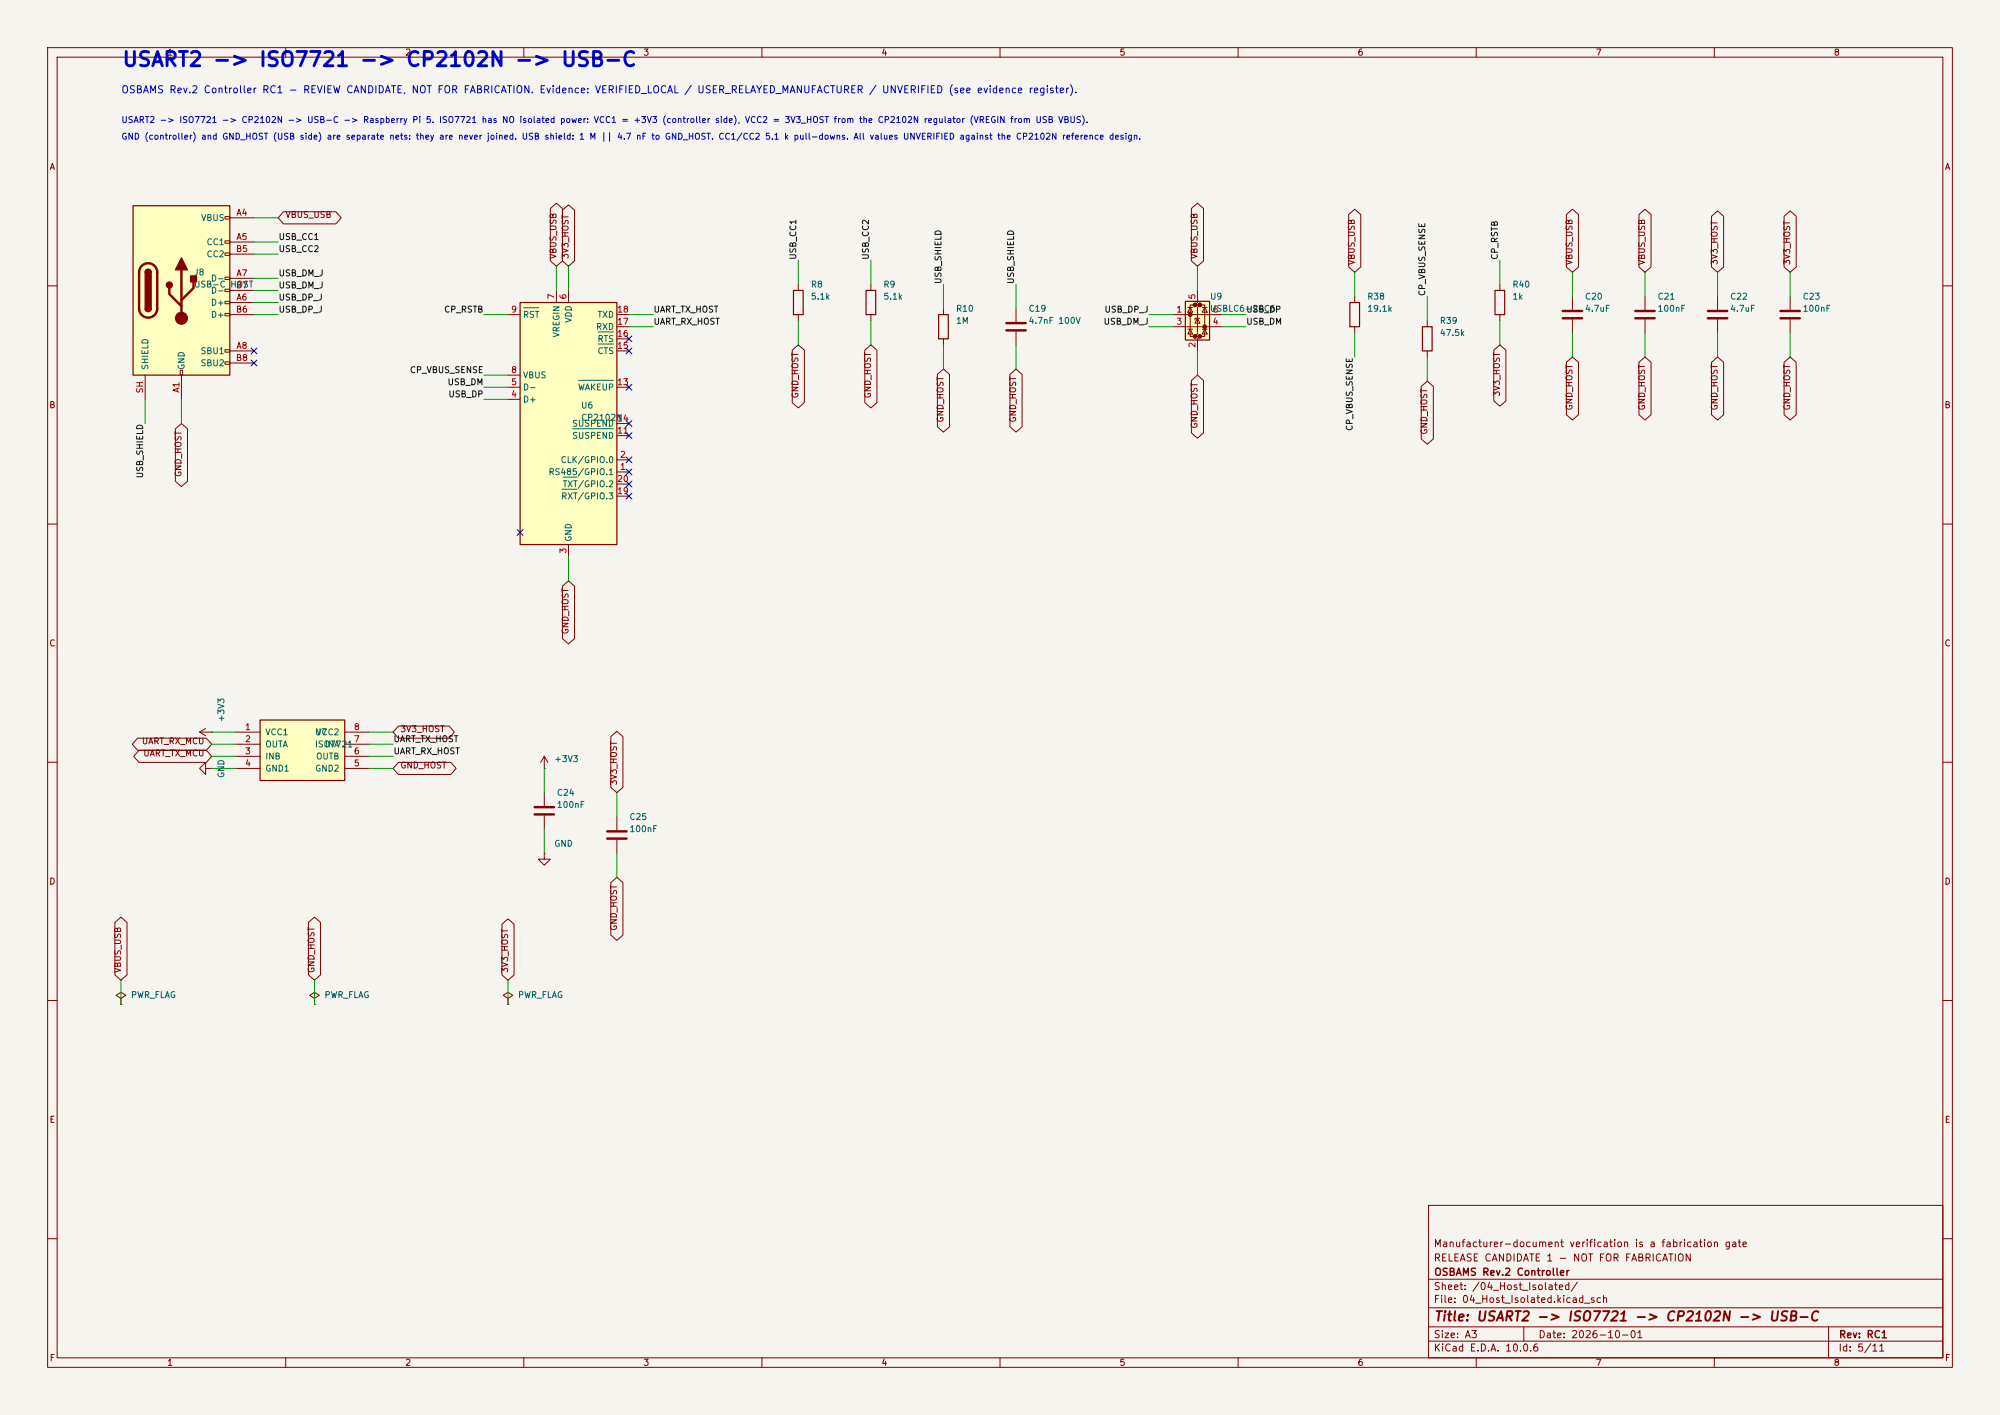
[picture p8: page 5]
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

SUSPEND 14 CTS 15 RTS 16 RXD 17 TXD 18 RXT/GPIO.3 19 TXT/GPIO.2 20 U6CP2102N

Manufacturer-document verification is a fabrication gate
RELEASE CANDIDATE 1 - NOT FOR FABRICATION
OSBAMS Rev.2 Controller
Sheet: /04_Host_Isolated/
File: 04_Host_Isolated.kicad_sch
Title: USART2 -> ISO7721 -> CP2102N -> USB-C

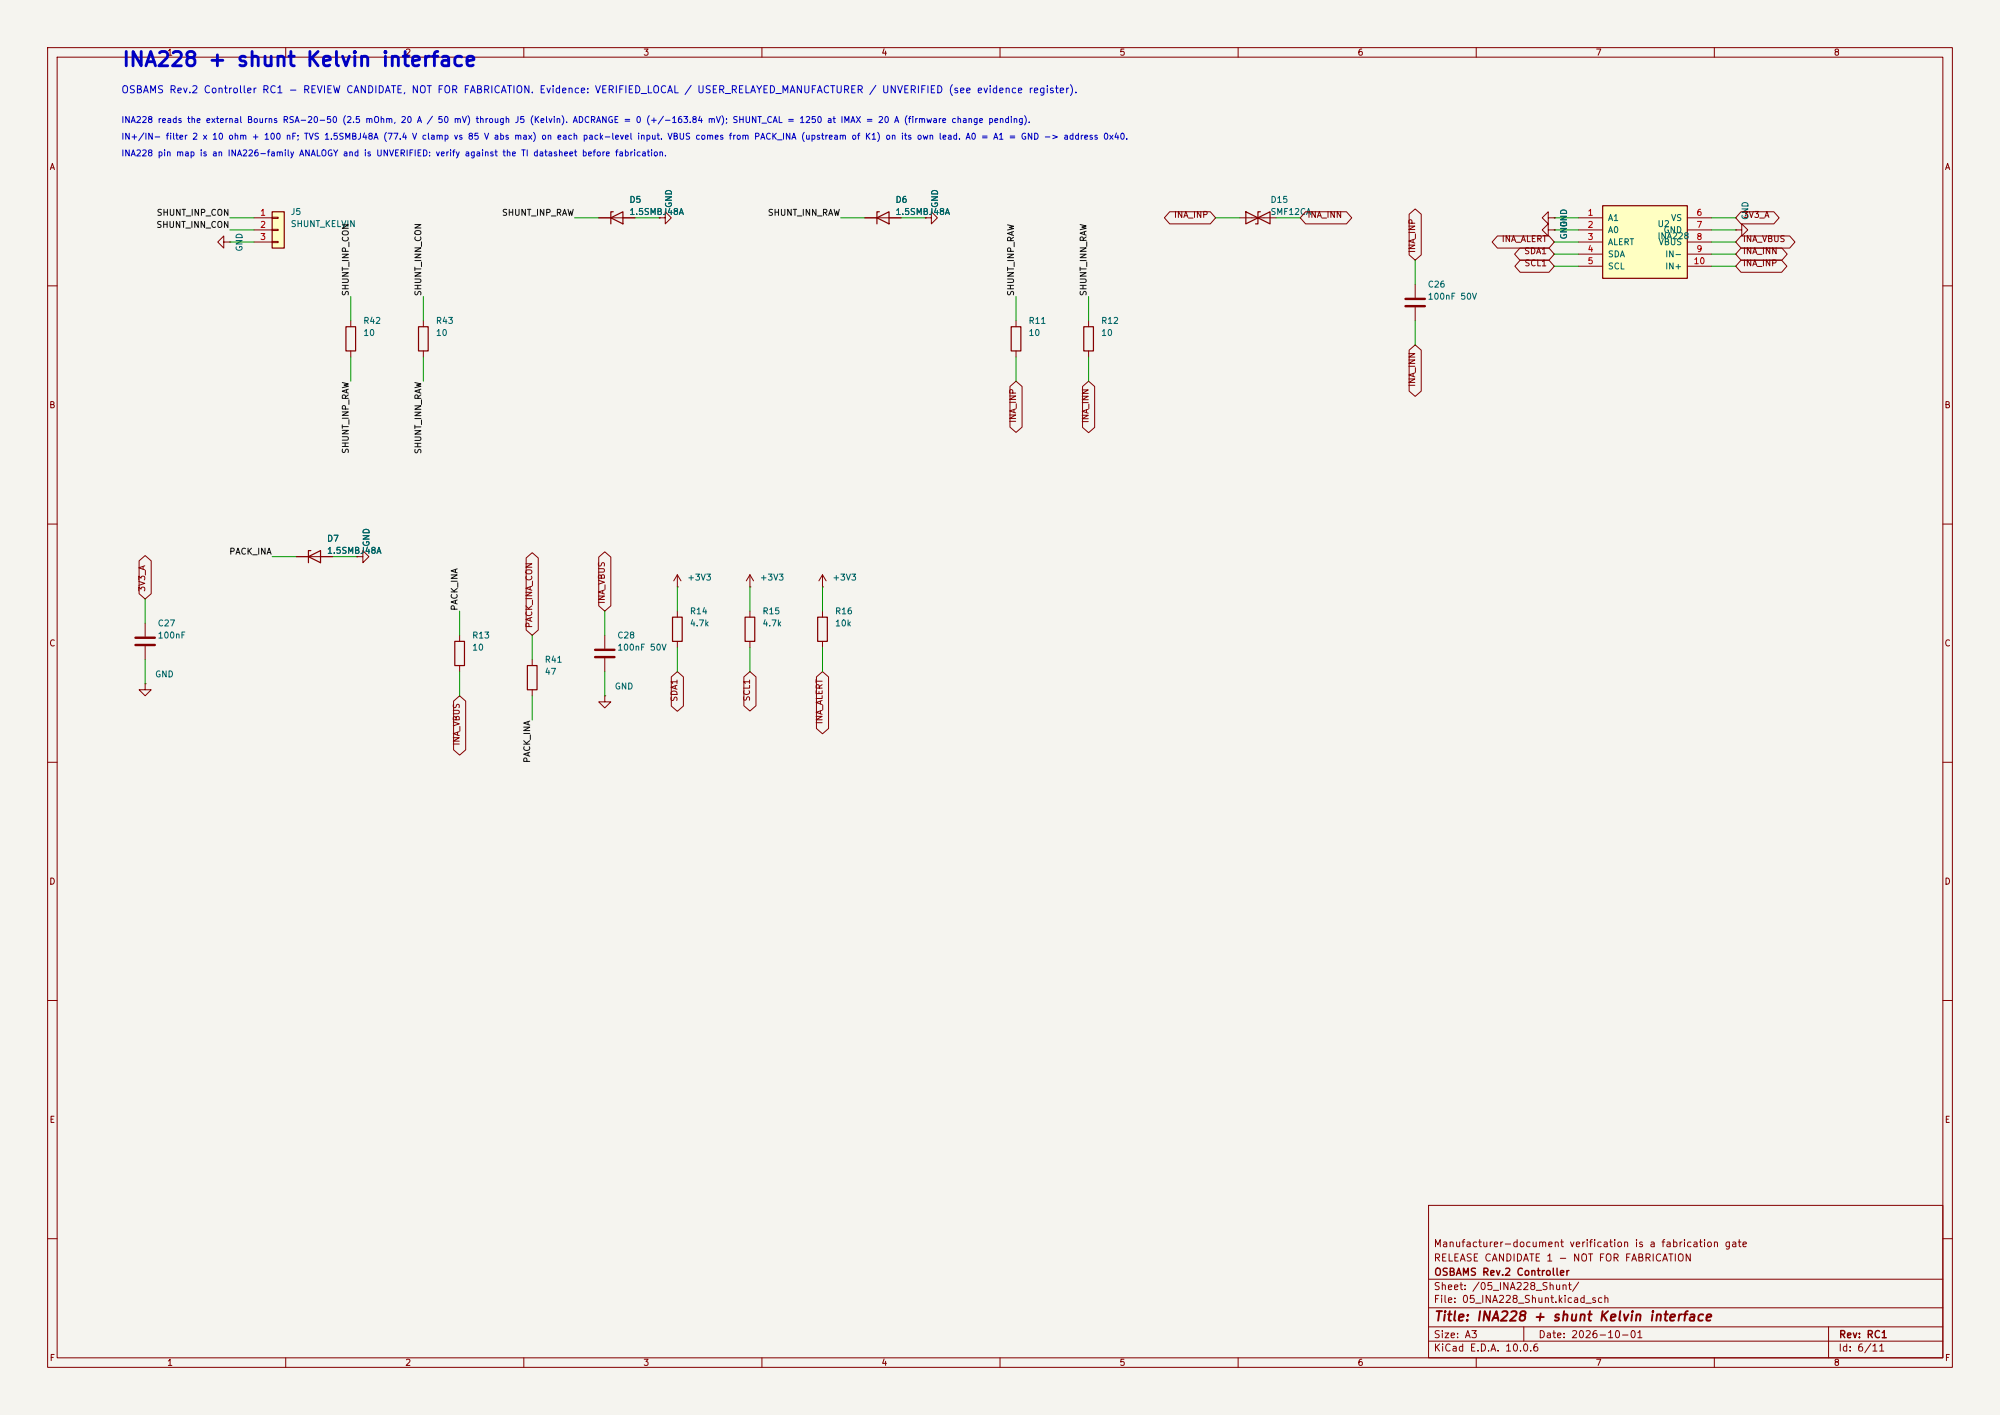
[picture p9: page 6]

IN+/IN- filter 2 x 10 ohm + 100 nF; TVS 1.5SMBJ48A (77.4 V clamp vs 85 V abs max) on each pack-level input. VBUS comes from PACK_INA (upstream of K1) on its own lead. A0 = A1 = GND -> address 0x40. OSBAMS Rev.2 Controller RC1 - REVIEW CANDIDATE, NOT FOR FABRICATION. Evidence: VERIFIED_LOCAL / USER_RELAYED_MANUFACTURER / UNVERIFIED (see evidence register).

INA228 reads the external Bourns RSA-20-50 (2.5 mOhm, 20 A / 50 mV) through J5 (Kelvin). ADCRANGE = 0 (+/-163.84 mV); SHUNT_CAL = 1250 at IMAX = 20 A (firmware change pending).

Manufacturer-document verification is a fabrication gate
RELEASE CANDIDATE 1 - NOT FOR FABRICATION
OSBAMS Rev.2 Controller
Sheet: /05_INA228_Shunt/
File: 05_INA228_Shunt.kicad_sch
Title: INA228 + shunt Kelvin interface

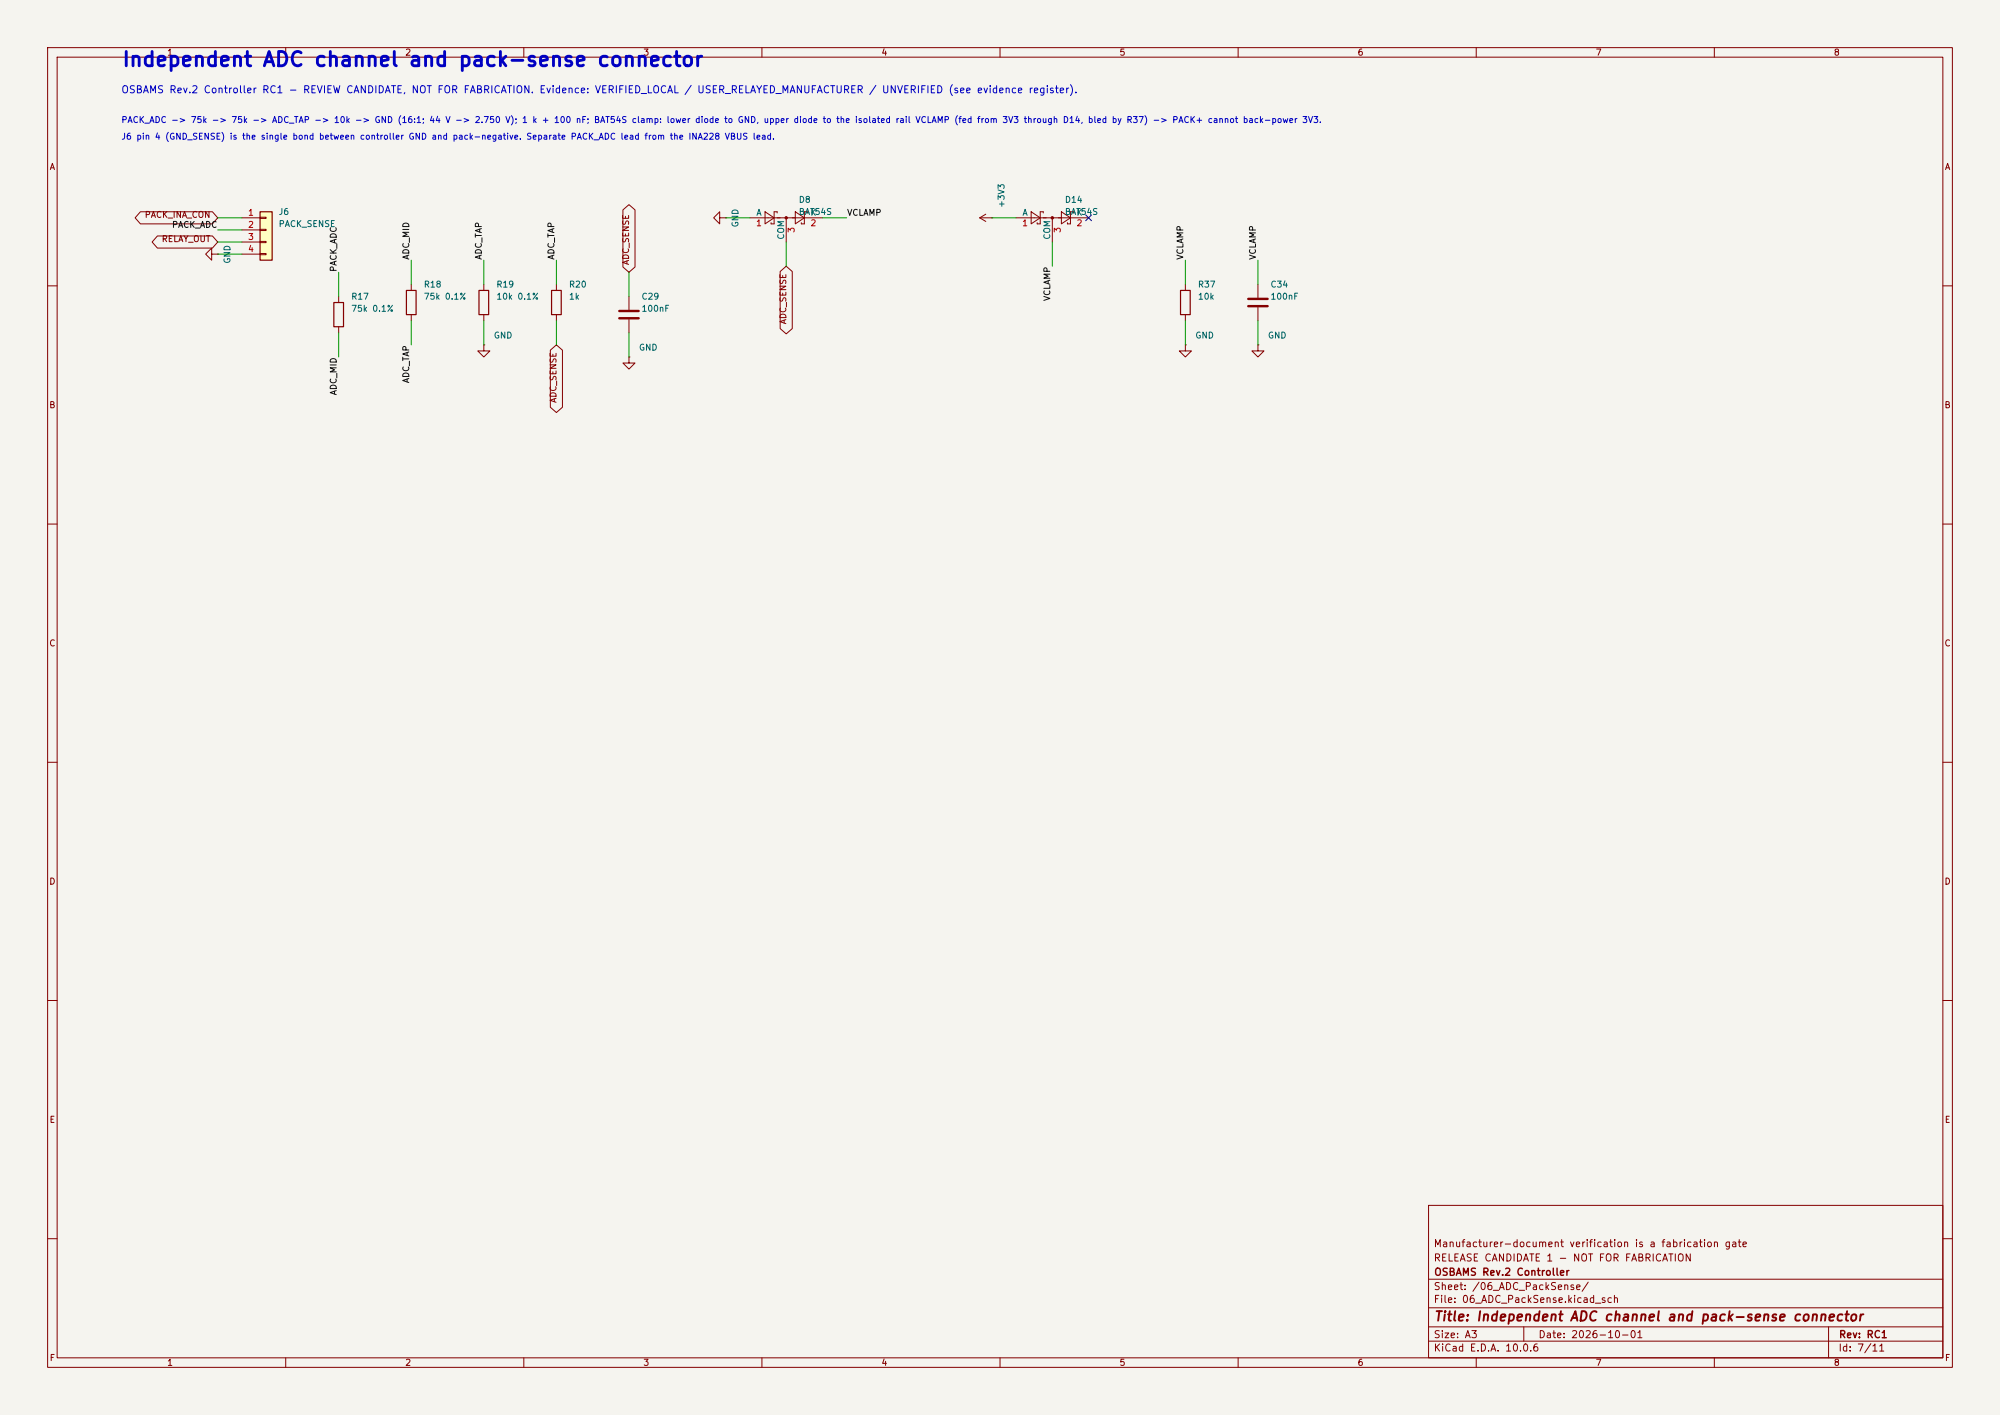
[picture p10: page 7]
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

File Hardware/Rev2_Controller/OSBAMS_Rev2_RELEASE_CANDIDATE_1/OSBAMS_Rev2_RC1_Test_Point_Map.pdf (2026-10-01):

0

OSBAMS Rev.2 Controller - test-point map (27 points) RC1.2e - REVIEW CANDIDATE - NOT RELEASED FOR FABRICATION

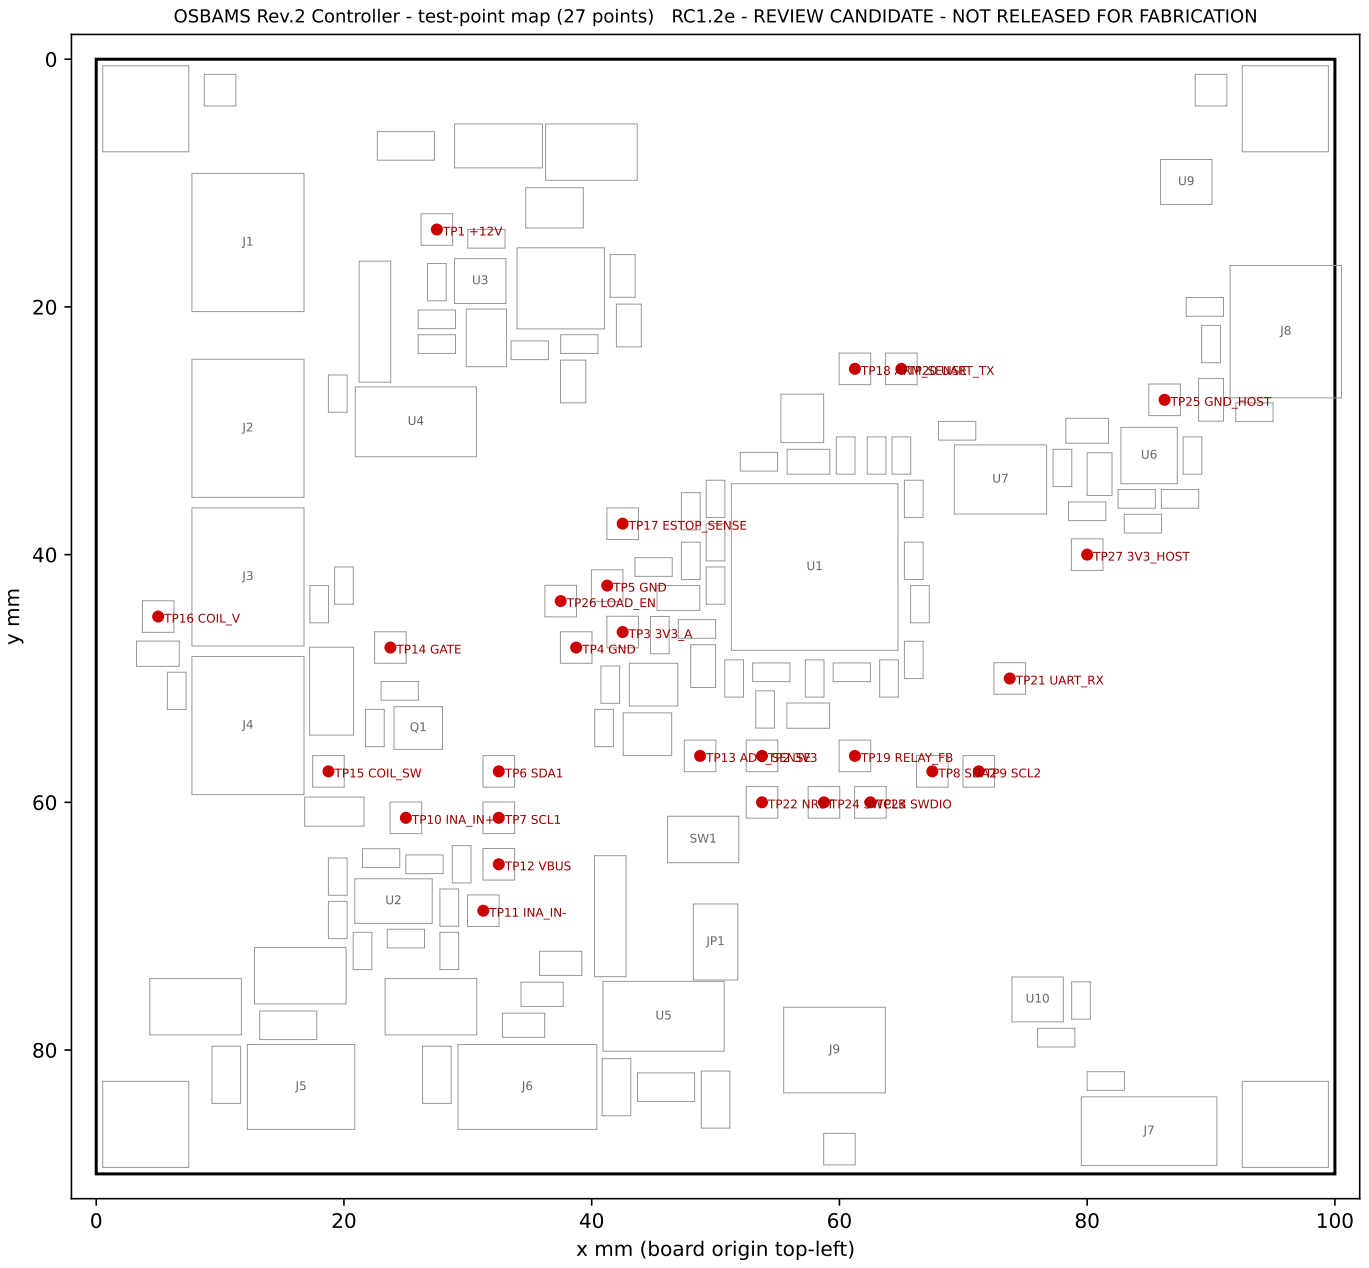
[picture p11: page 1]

x mm (board origin top-left)

Ref | Label | Net | x,y mm
TP1 | +12V | +12V | (27.5, 13.8)
TP2 | 3V3 | +3V3 | (53.8, 56.2)
TP3 | 3V3_A | 3V3_A | (42.5, 46.2)
TP4 | GND | GND | (38.8, 47.5)
TP5 | GND | GND | (41.2, 42.5)
TP6 | SDA1 | SDA1 | (32.5, 57.5)
TP7 | SCL1 | SCL1 | (32.5, 61.2)
TP8 | SDA2 | SDA2 | (67.5, 57.5)
TP9 | SCL2 | SCL2 | (71.2, 57.5)
TP10 | INA_IN+ | INA_INP | (25.0, 61.2)
TP11 | INA_IN- | INA_INN | (31.2, 68.8)
TP12 | VBUS | INA_VBUS | (32.5, 65.0)
TP13 | ADC_SENSE | ADC_SENSE | (48.8, 56.2)
TP14 | GATE | GATE | (23.8, 47.5)
TP15 | COIL_SW | COIL_SW | (18.8, 57.5)
TP16 | COIL_V | COIL_V | (5.0, 45.0)
TP17 | ESTOP_SENSE | ESTOP_SENSE | (42.5, 37.5)
TP18 | ARM_SENSE | ARM_SENSE | (61.2, 25.0)
TP19 | RELAY_FB | RELAY_FB | (61.2, 56.2)
TP20 | UART_TX | UART_TX_MCU | (65.0, 25.0)
TP21 | UART_RX | UART_RX_MCU | (73.8, 50.0)
TP22 | NRST | NRST | (53.8, 60.0)
TP23 | SWDIO | SWDIO | (62.5, 60.0)
TP24 | SWCLK | SWCLK | (58.8, 60.0)
TP25 | GND_HOST | GND_HOST | (86.2, 27.5)
TP26 | LOAD_EN | LOAD_EN | (37.5, 43.8)
TP27 | 3V3_HOST | 3V3_HOST | (80.0, 40.0)

## Test-point list

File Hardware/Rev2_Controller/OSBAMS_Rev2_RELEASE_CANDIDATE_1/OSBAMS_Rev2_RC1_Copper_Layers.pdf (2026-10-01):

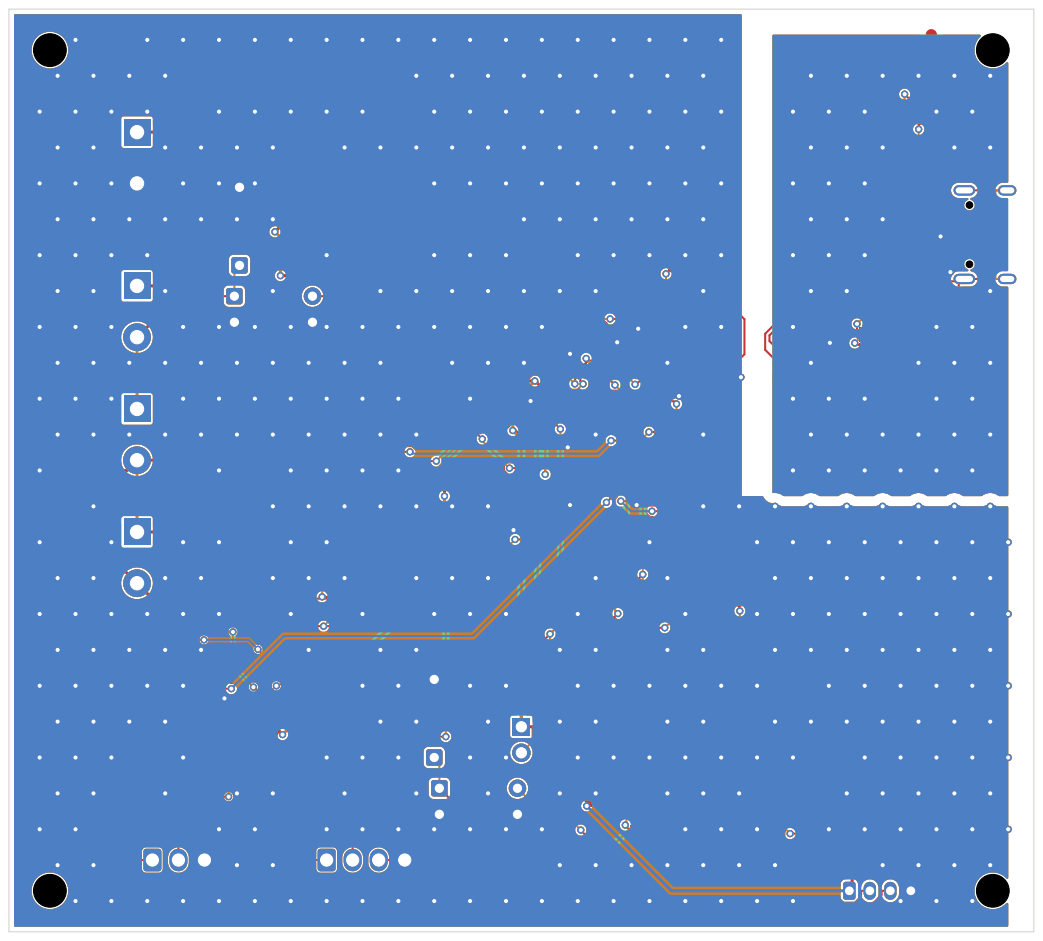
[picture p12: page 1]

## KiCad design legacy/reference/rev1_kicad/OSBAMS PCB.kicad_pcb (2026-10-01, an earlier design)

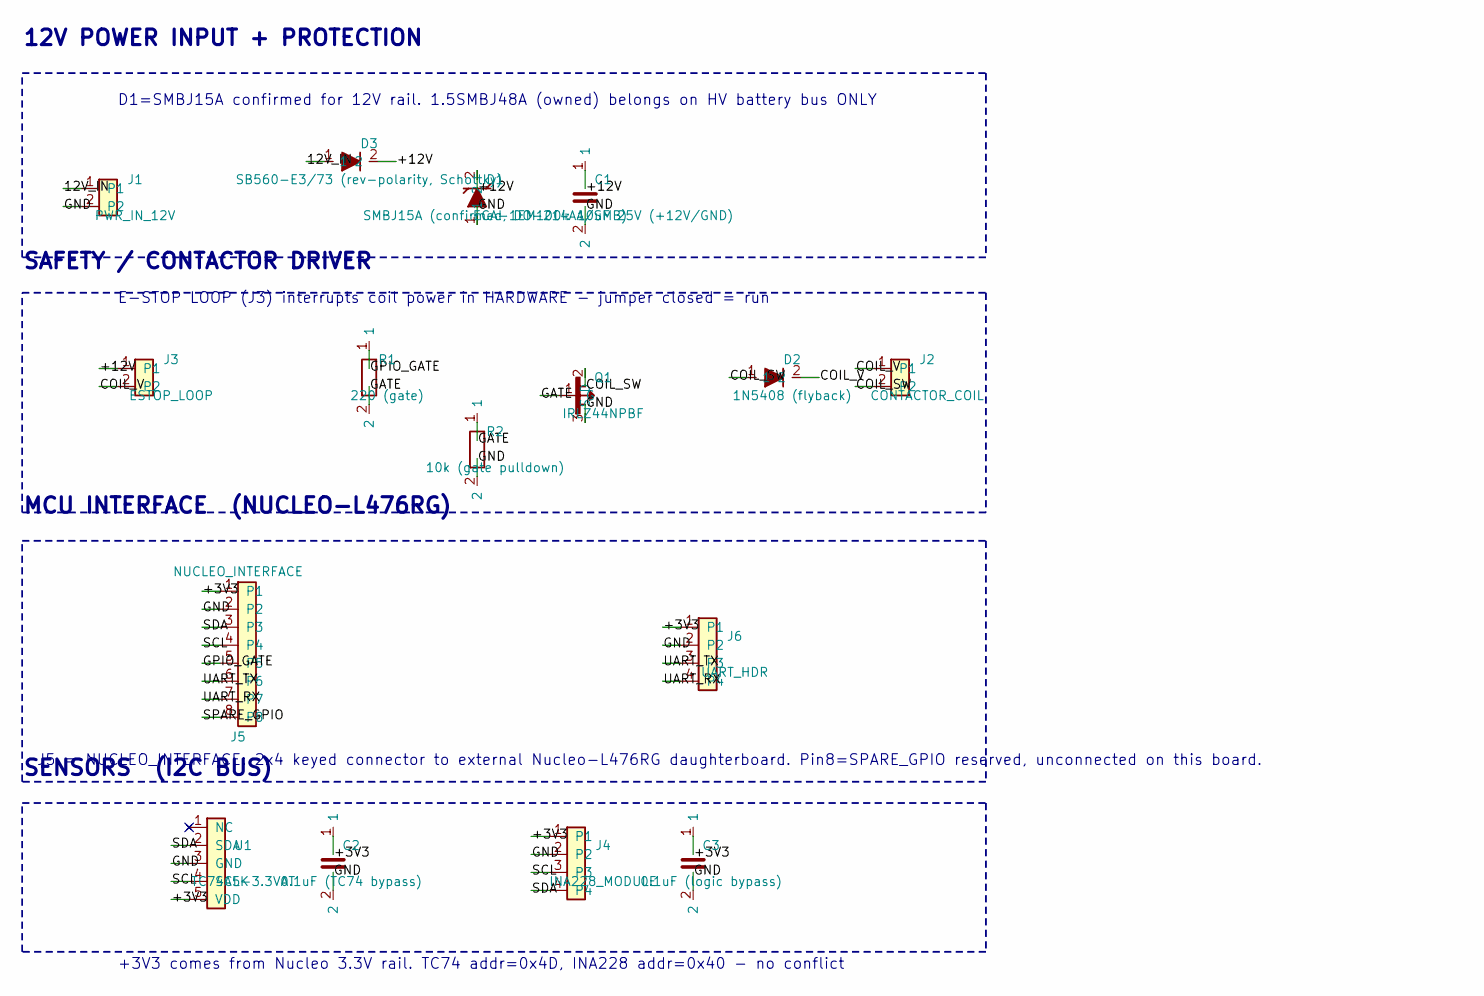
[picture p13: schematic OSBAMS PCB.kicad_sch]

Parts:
C1: ECA-1EM100I: 10uF 25V (+12V/GND); CP_Radial_D5.0mm_P2.00mm
C2: 0.1uF (TC74 bypass); C_Disc_D5.0mm_W2.5mm_P5.00mm
C3: 0.1uF (logic bypass); C_Disc_D5.0mm_W2.5mm_P5.00mm
D1: SMBJ15A (confirmed, DO-214AA/SMB); D_SMB
D2: 1N5408 (flyback); D_DO-201AD_P15.24mm_Horizontal
D3: SB560-E3/73 (rev-polarity, Schottky); D_DO-201AD_P15.24mm_Horizontal
J1: PWR_IN_12V; TerminalBlock_MaiXu_MX126-5.0-02P_1x02_P5.00mm
J2: CONTACTOR_COIL; TerminalBlock_MaiXu_MX126-5.0-02P_1x02_P5.00mm
J3: ESTOP_LOOP; TerminalBlock_MaiXu_MX126-5.0-02P_1x02_P5.00mm
J4: INA228_MODULE; PinHeader_1x04_P2.54mm_Vertical
J5: NUCLEO_INTERFACE; PinHeader_2x04_P2.54mm_Vertical
J6: UART_HDR; FanPinHeader_1x04_P2.54mm_Vertical
Q1: IRLZ44NPBF; TO-220-3_Vertical
R1: 220 (gate); R_Axial_DIN0207_L6.3mm_D2.5mm_P10.16mm_Horizontal
R2: 10k (gate pulldown); R_Axial_DIN0207_L6.3mm_D2.5mm_P10.16mm_Horizontal
U1: TC74A5-3.3VAT; TO-220-5_Vertical

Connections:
/12V_IN: D3.1, J1.1
/+3V3: C2.1, C3.1, J4.1, J5.1, J6.1, U1.5 (VDD)
/+12V: C1.1, D1.2, D3.2, J3.1
/COIL_SW: D2.1, J2.2, Q1.2 (D)
/COIL_V: D2.2, J2.1, J3.2
/GATE: Q1.1 (G), R1.2, R2.1
/GND: C1.2, C2.2, C3.2, D1.1, J1.2, J4.2, J5.2, J6.2, Q1.3 (S), R2.2, U1.3 (GND)
/GPIO_GATE: J5.5, R1.1
/SCL: J4.3, J5.4, U1.4 (SCLK)
/SDA: J4.4, J5.3, U1.2 (SDA)
/SPARE_GPIO: J5.8
/UART_RX: J5.7, J6.4
/UART_TX: J5.6, J6.3

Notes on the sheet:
+3V3 comes from Nucleo 3.3V rail. TC74 addr=0x4D, INA228 addr=0x40 - no conflict
SENSORS (I2C BUS)
D1=SMBJ15A confirmed for 12V rail. 1.5SMBJ48A (owned) belongs on HV battery bus ONLY
MCU INTERFACE (NUCLEO-L476RG)
E-STOP LOOP (J3) interrupts coil power in HARDWARE - jumper closed = run
12V POWER INPUT + PROTECTION
SAFETY / CONTACTOR DRIVER
J5 = NUCLEO_INTERFACE: 2x4 keyed connector to external Nucleo-L476RG daughterboard. Pin8=SPARE_GPIO reserved, unconnected on this board.

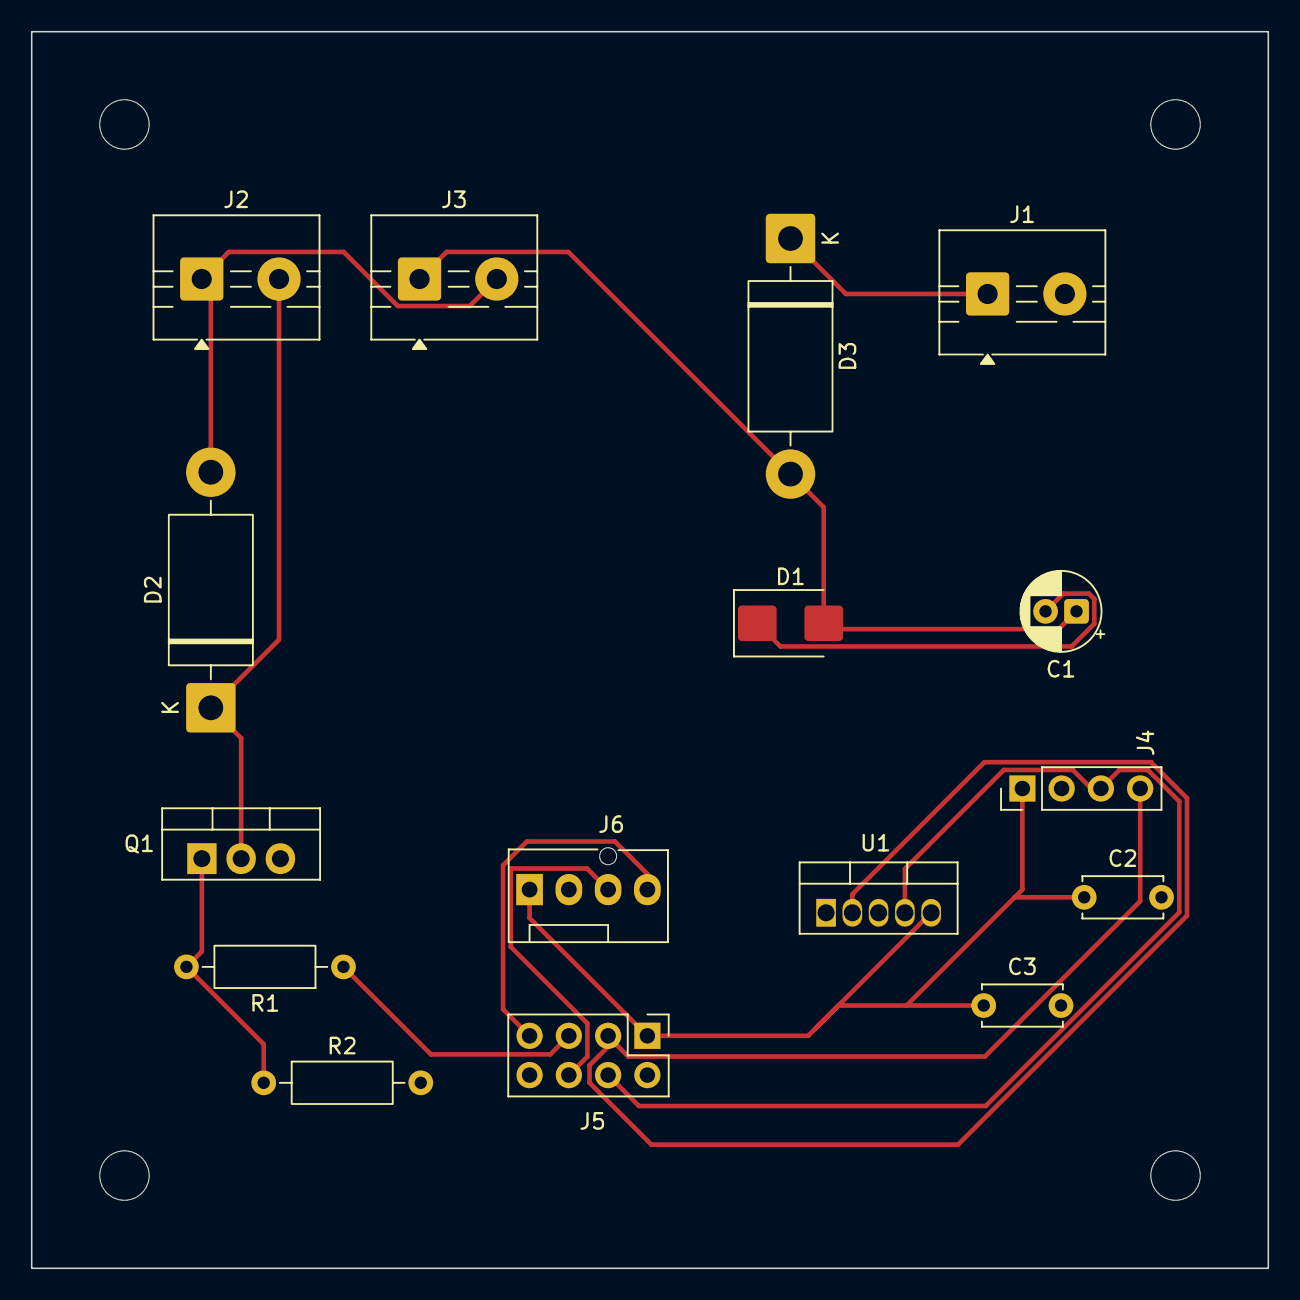
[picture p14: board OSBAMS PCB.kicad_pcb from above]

Board: 2 copper layers, 80.0 x 80.0 mm, 20 parts (0 on the bottom side), 12 nets.

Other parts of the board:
MH1, MH2, MH3, MH4: MountingHole_3.2mm_M3

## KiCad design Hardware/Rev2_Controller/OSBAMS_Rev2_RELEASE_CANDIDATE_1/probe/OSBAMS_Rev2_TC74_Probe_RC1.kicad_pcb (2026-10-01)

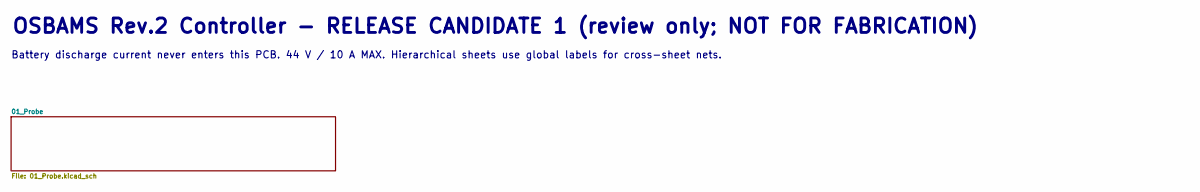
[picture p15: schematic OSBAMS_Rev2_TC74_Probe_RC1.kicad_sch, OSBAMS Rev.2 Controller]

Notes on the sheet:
Battery discharge current never enters this PCB. 44 V / 10 A MAX. Hierarchical sheets use global labels for cross-sheet nets.
OSBAMS Rev.2 Controller - RELEASE CANDIDATE 1 (review only; NOT FOR FABRICATION)

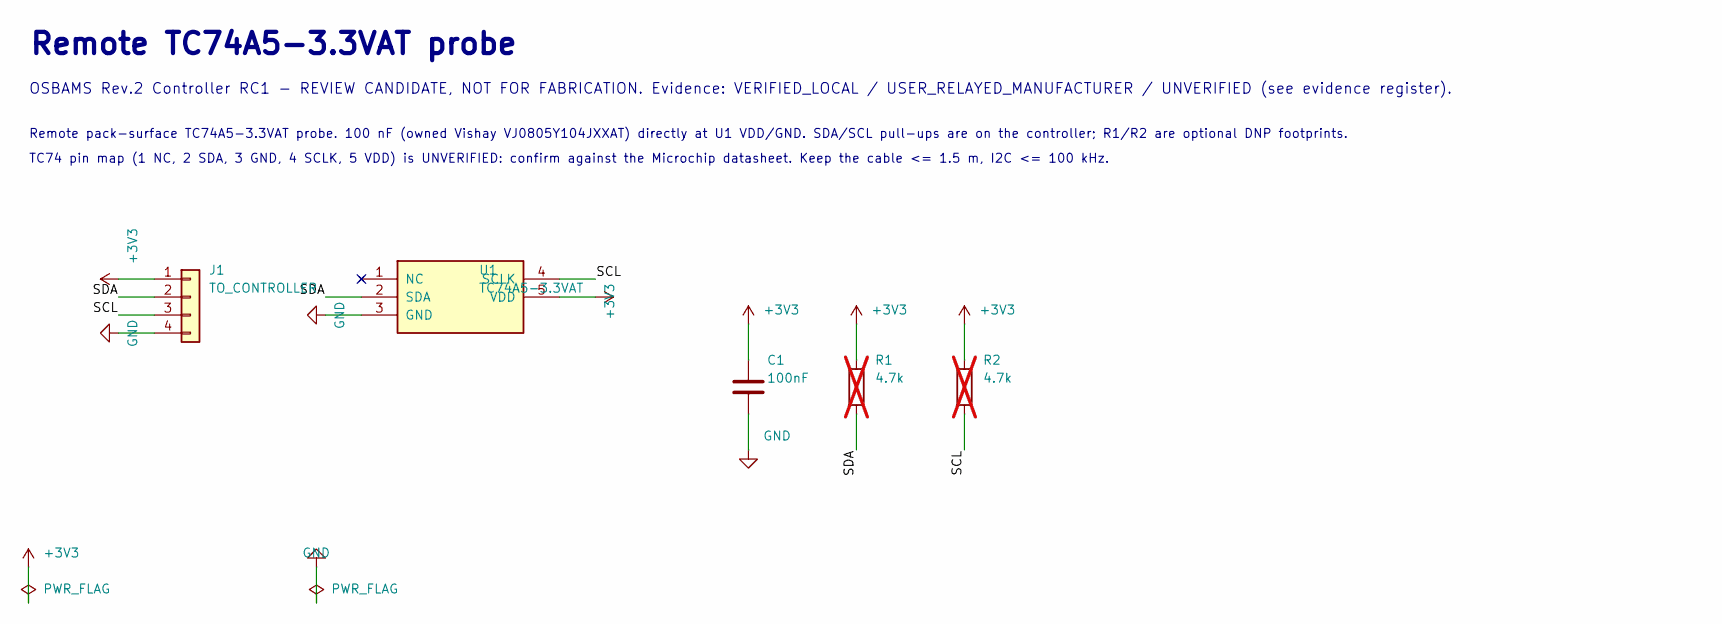
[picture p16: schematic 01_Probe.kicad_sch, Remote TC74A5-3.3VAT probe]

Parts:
C1: 100nF; C_0805_2012Metric; MPN VJ0805Y104JXXAT
J1: TO_CONTROLLER; JST_PH_B4B-PH-K_1x04_P2.00mm_Vertical; MPN B4B-PH-K-S
R1, R2: 4.7k; R_0603_1608Metric; MPN CRCW06034K70FKEA; not fitted
U1: TC74A5-3.3VAT; TO-220-5_P3.4x3.7mm_StaggerOdd_Lead3.8mm_Vertical; MPN TC74A5-3.3VAT

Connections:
+3V3: C1.1, J1.1, R1.1, R2.1, U1.5 (VDD)
GND: C1.2, J1.4, U1.3 (GND)
SCL: J1.3, R2.2, U1.4 (SCLK)
SDA: J1.2, R1.2, U1.2 (SDA)

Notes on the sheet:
Remote pack-surface TC74A5-3.3VAT probe. 100 nF (owned Vishay VJ0805Y104JXXAT) directly at U1 VDD/GND. SDA/SCL pull-ups are on the controller; R1/R2 are optional DNP footprints.
TC74 pin map (1 NC, 2 SDA, 3 GND, 4 SCLK, 5 VDD) is UNVERIFIED: confirm against the Microchip datasheet. Keep the cable <= 1.5 m, I2C <= 100 kHz.
OSBAMS Rev.2 Controller RC1 - REVIEW CANDIDATE, NOT FOR FABRICATION. Evidence: VERIFIED_LOCAL / USER_RELAYED_MANUFACTURER / UNVERIFIED (see evidence register).
Remote TC74A5-3.3VAT probe

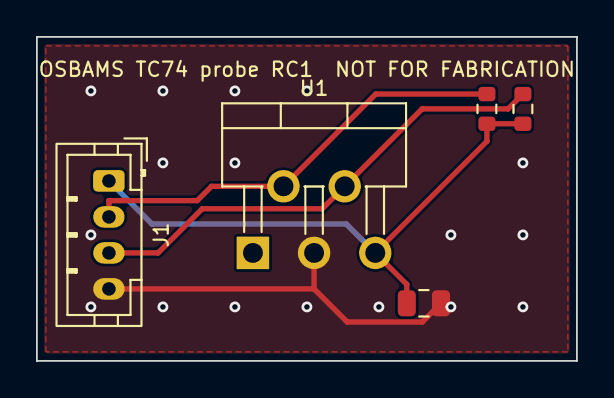
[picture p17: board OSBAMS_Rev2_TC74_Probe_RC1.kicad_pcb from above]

Board: 2 copper layers, 30.0 x 18.0 mm, 5 parts (0 on the bottom side), 4 nets.

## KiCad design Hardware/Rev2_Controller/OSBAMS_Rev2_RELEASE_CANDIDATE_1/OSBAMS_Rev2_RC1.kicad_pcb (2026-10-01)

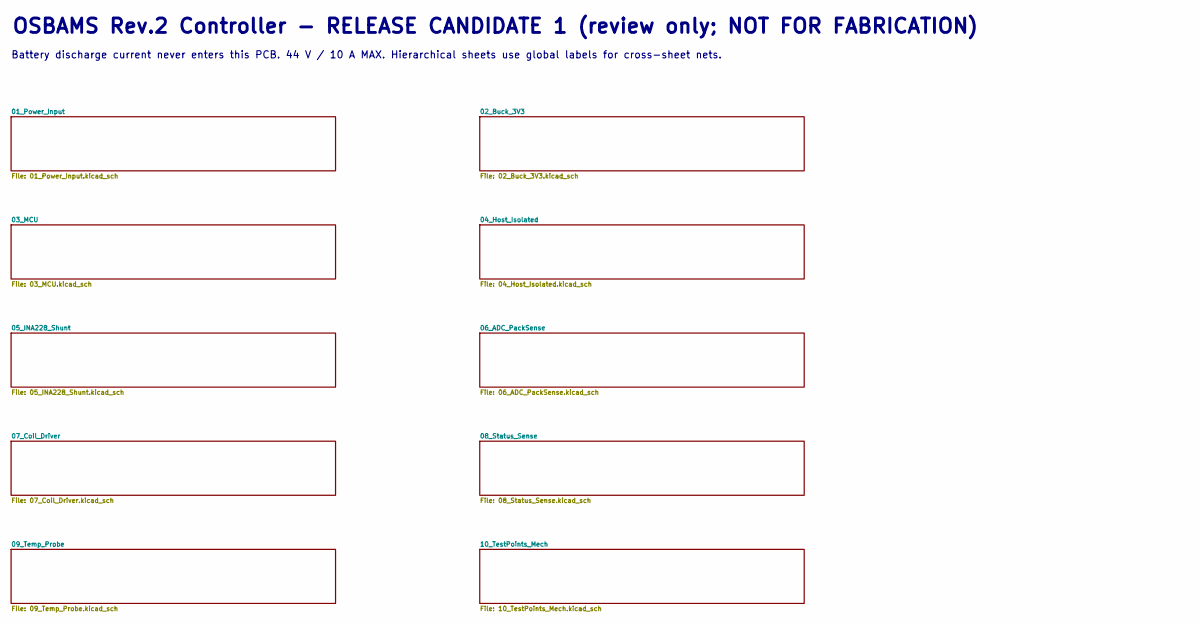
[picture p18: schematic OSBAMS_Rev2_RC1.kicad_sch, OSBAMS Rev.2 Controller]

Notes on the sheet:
OSBAMS Rev.2 Controller - RELEASE CANDIDATE 1 (review only; NOT FOR FABRICATION)
Battery discharge current never enters this PCB. 44 V / 10 A MAX. Hierarchical sheets use global labels for cross-sheet nets.

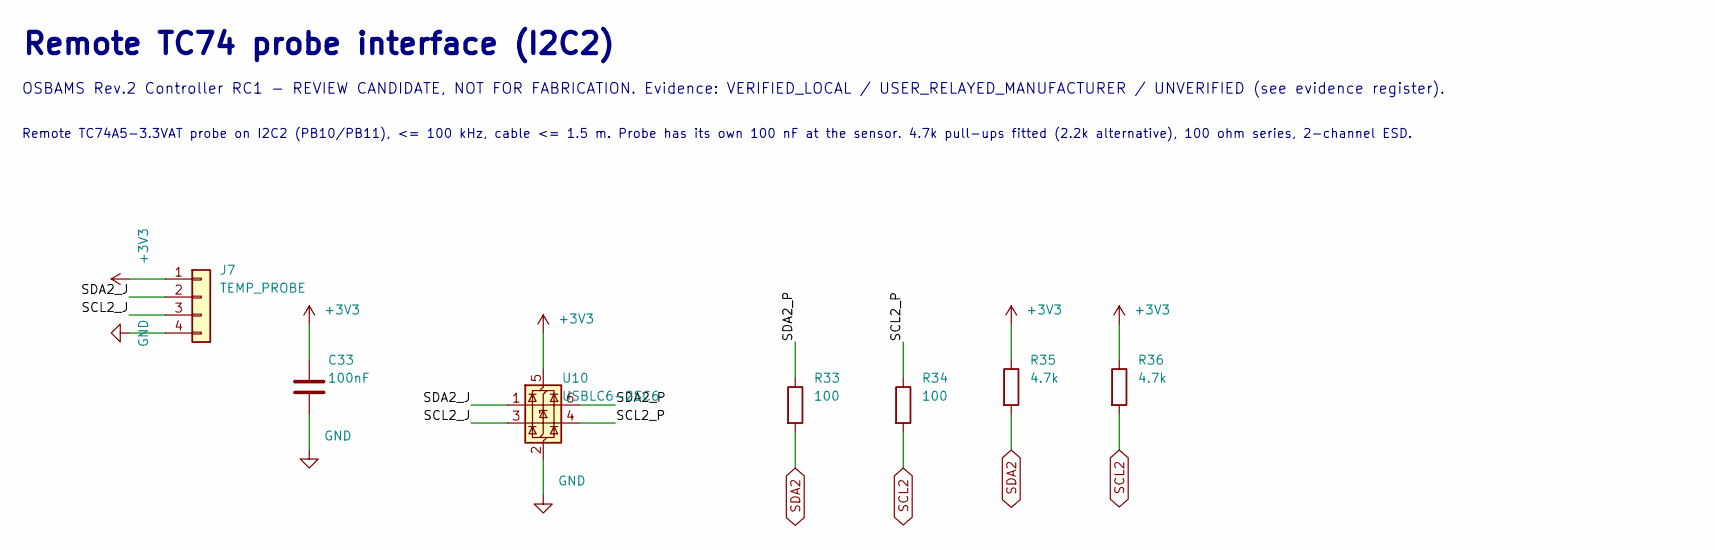
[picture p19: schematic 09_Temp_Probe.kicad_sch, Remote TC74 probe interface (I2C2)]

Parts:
C33: 100nF; C_0603_1608Metric; MPN GRM188R71H104KA93D
J7: TEMP_PROBE; JST_PH_B4B-PH-K_1x04_P2.00mm_Vertical; MPN B4B-PH-K-S
R33, R34: 100; R_0603_1608Metric; MPN CRCW0603100RFKEA
R35, R36: 4.7k; R_0603_1608Metric; MPN CRCW06034K70FKEA
U10: USBLC6-2SC6; SOT-23-6; MPN USBLC6-2SC6

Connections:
+3V3: C33.1, J7.1, R35.1, R36.1, U10.5 (VBUS); also elsewhere on the board
/09_Temp_Probe/SCL2_J: J7.3, U10.3 (I/O2)
/09_Temp_Probe/SCL2_P: R34.1, U10.4 (I/O2)
/09_Temp_Probe/SDA2_J: J7.2, U10.1 (I/O1)
/09_Temp_Probe/SDA2_P: R33.1, U10.6 (I/O1)
GND: C33.2, J7.4, U10.2 (GND); also elsewhere on the board
SCL2: R34.2, R36.2; also elsewhere on the board
SDA2: R33.2, R35.2; also elsewhere on the board

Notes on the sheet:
OSBAMS Rev.2 Controller RC1 - REVIEW CANDIDATE, NOT FOR FABRICATION. Evidence: VERIFIED_LOCAL / USER_RELAYED_MANUFACTURER / UNVERIFIED (see evidence register).
Remote TC74 probe interface (I2C2)
Remote TC74A5-3.3VAT probe on I2C2 (PB10/PB11), <= 100 kHz, cable <= 1.5 m. Probe has its own 100 nF at the sensor. 4.7k pull-ups fitted (2.2k alternative), 100 ohm series, 2-channel ESD.

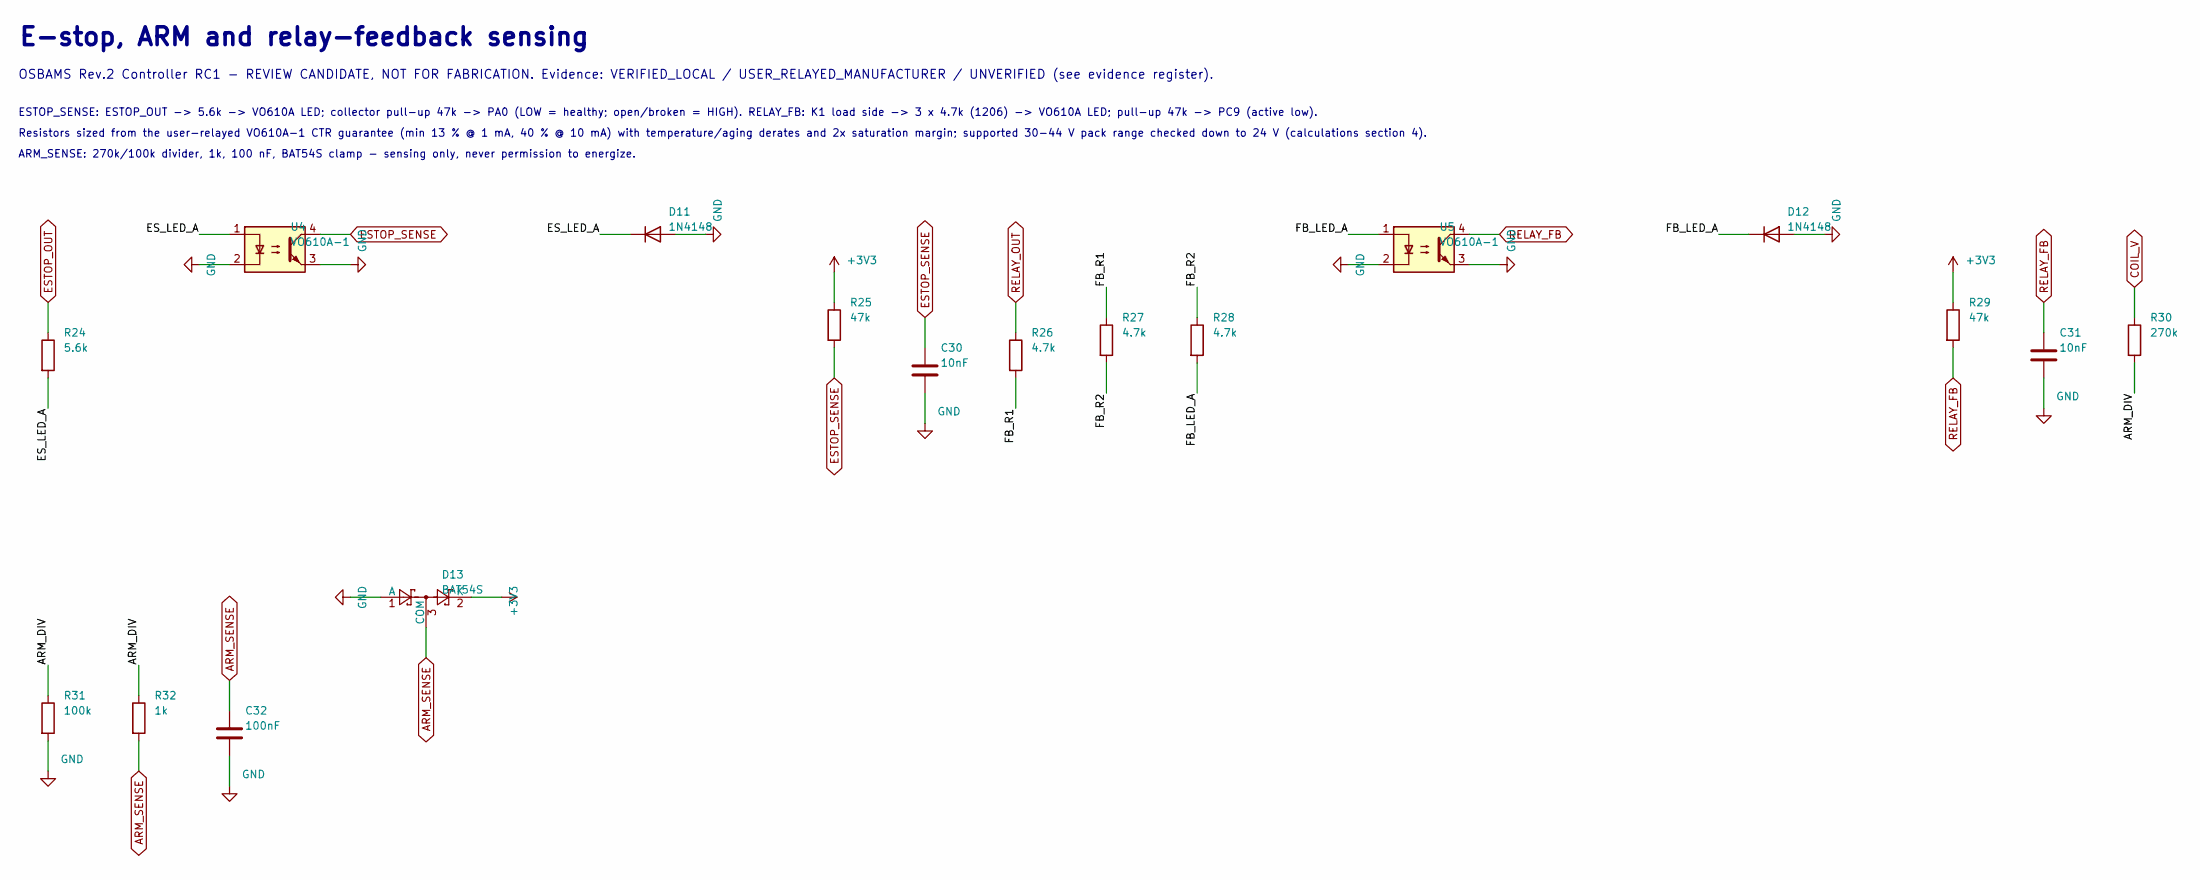
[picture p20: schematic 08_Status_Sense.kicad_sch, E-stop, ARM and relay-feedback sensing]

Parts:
C30, C31: 10nF; C_0603_1608Metric; MPN GRM188R71H103KA01D
C32: 100nF; C_0603_1608Metric; MPN GRM188R71H104KA93D
D11, D12: 1N4148; D_DO-35_SOD27_P7.62mm_Horizontal; MPN 1N4148
D13: BAT54S; SOT-23; MPN BAT54S,215
R24: 5.6k; R_0603_1608Metric; MPN CRCW06035K60FKEA
R25, R29: 47k; R_0603_1608Metric; MPN CRCW060347K0FKEA
R26, R27, R28: 4.7k; R_1206_3216Metric; MPN CRCW12064K70FKEA
R30: 270k; R_0603_1608Metric; MPN CRCW0603270KFKEA
R31: 100k; R_0603_1608Metric; MPN CRCW0603100KFKEA
R32: 1k; R_0603_1608Metric; MPN CRCW06031K00FKEA
U4, U5: VO610A-1; DIP-4_W7.62mm; MPN VO610A-1

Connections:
+3V3: D13.2 (K), R25.1, R29.1; also elsewhere on the board
/08_Status_Sense/ARM_DIV: R30.2, R31.1, R32.1
/08_Status_Sense/ES_LED_A: D11.1 (K), R24.2, U4.1
/08_Status_Sense/FB_LED_A: D12.1 (K), R28.2, U5.1
/08_Status_Sense/FB_R1: R26.2, R27.1
/08_Status_Sense/FB_R2: R27.2, R28.1
ARM_SENSE: C32.1, D13.3 (COM), R32.2; also elsewhere on the board
COIL_V: R30.1; also elsewhere on the board
ESTOP_OUT: R24.1; also elsewhere on the board
ESTOP_SENSE: C30.1, R25.2, U4.4; also elsewhere on the board
GND: C30.2, C31.2, C32.2, D11.2 (A), D12.2 (A), D13.1 (A), R31.2, U4.2, U4.3, U5.2, U5.3; also elsewhere on the board
RELAY_FB: C31.1, R29.2, U5.4; also elsewhere on the board
RELAY_OUT: R26.1; also elsewhere on the board

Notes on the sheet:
OSBAMS Rev.2 Controller RC1 - REVIEW CANDIDATE, NOT FOR FABRICATION. Evidence: VERIFIED_LOCAL / USER_RELAYED_MANUFACTURER / UNVERIFIED (see evidence register).
Resistors sized from the user-relayed VO610A-1 CTR guarantee (min 13 % @ 1 mA, 40 % @ 10 mA) with temperature/aging derates and 2x saturation margin; supported 30-44 V pack range checked down to 24 V (calculations section 4).
E-stop, ARM and relay-feedback sensing
ARM_SENSE: 270k/100k divider, 1k, 100 nF, BAT54S clamp - sensing only, never permission to energize.
ESTOP_SENSE: ESTOP_OUT -> 5.6k -> VO610A LED; collector pull-up 47k -> PA0 (LOW = healthy; open/broken = HIGH). RELAY_FB: K1 load side -> 3 x 4.7k (1206) -> VO610A LED; pull-up 47k -> PC9 (active low).

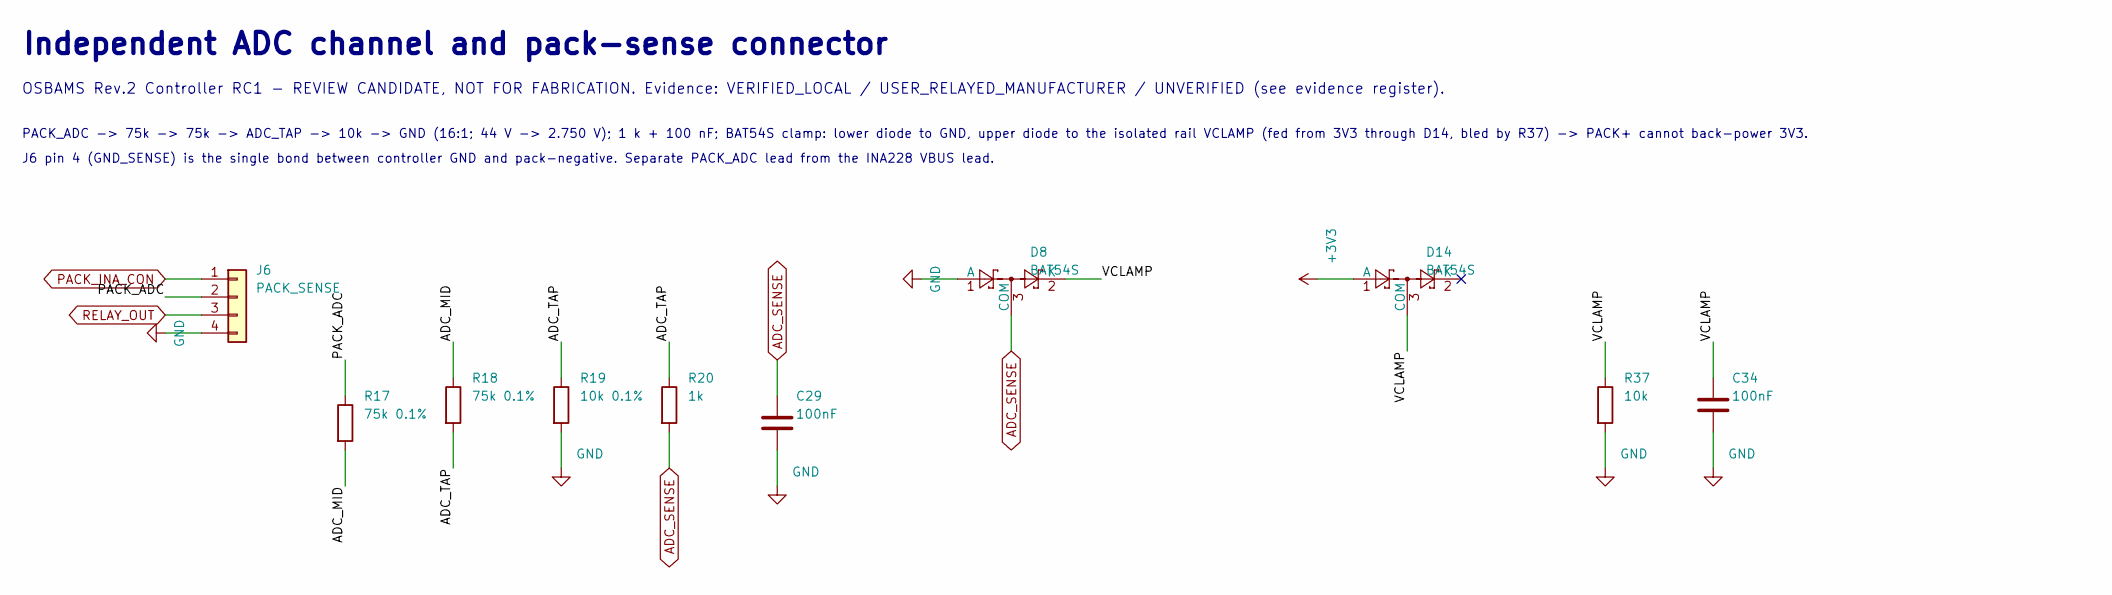
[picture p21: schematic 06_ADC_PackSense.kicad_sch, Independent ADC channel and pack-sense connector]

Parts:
C29, C34: 100nF; C_0603_1608Metric; MPN GRM188R71H104KA93D
D8, D14: BAT54S; SOT-23; MPN BAT54S,215
J6: PACK_SENSE; Molex_KK-254_AE-6410-04A_1x04_P2.54mm_Vertical; MPN 22-27-2041
R17, R18: 75k 0.1%; R_0805_2012Metric; MPN TNPW080575K0BEEA
R19: 10k 0.1%; R_0805_2012Metric; MPN TNPW080510K0BEEA
R20: 1k; R_0603_1608Metric; MPN CRCW06031K00FKEA
R37: 10k; R_0603_1608Metric; MPN CRCW060310K0FKEA

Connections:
+3V3: D14.1 (A); also elsewhere on the board
/06_ADC_PackSense/ADC_MID: R17.2, R18.1
/06_ADC_PackSense/ADC_TAP: R18.2, R19.1, R20.1
/06_ADC_PackSense/PACK_ADC: J6.2, R17.1
/06_ADC_PackSense/VCLAMP: C34.1, D8.2 (K), D14.3 (COM), R37.1
ADC_SENSE: C29.1, D8.3 (COM), R20.2; also elsewhere on the board
GND: C29.2, C34.2, D8.1 (A), J6.4, R19.2, R37.2; also elsewhere on the board
PACK_INA_CON: J6.1; also elsewhere on the board
RELAY_OUT: J6.3; also elsewhere on the board

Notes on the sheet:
Independent ADC channel and pack-sense connector
PACK_ADC -> 75k -> 75k -> ADC_TAP -> 10k -> GND (16:1; 44 V -> 2.750 V); 1 k + 100 nF; BAT54S clamp: lower diode to GND, upper diode to the isolated rail VCLAMP (fed from 3V3 through D14, bled by R37) -> PACK+ cannot back-power 3V3.
OSBAMS Rev.2 Controller RC1 - REVIEW CANDIDATE, NOT FOR FABRICATION. Evidence: VERIFIED_LOCAL / USER_RELAYED_MANUFACTURER / UNVERIFIED (see evidence register).
J6 pin 4 (GND_SENSE) is the single bond between controller GND and pack-negative. Separate PACK_ADC lead from the INA228 VBUS lead.

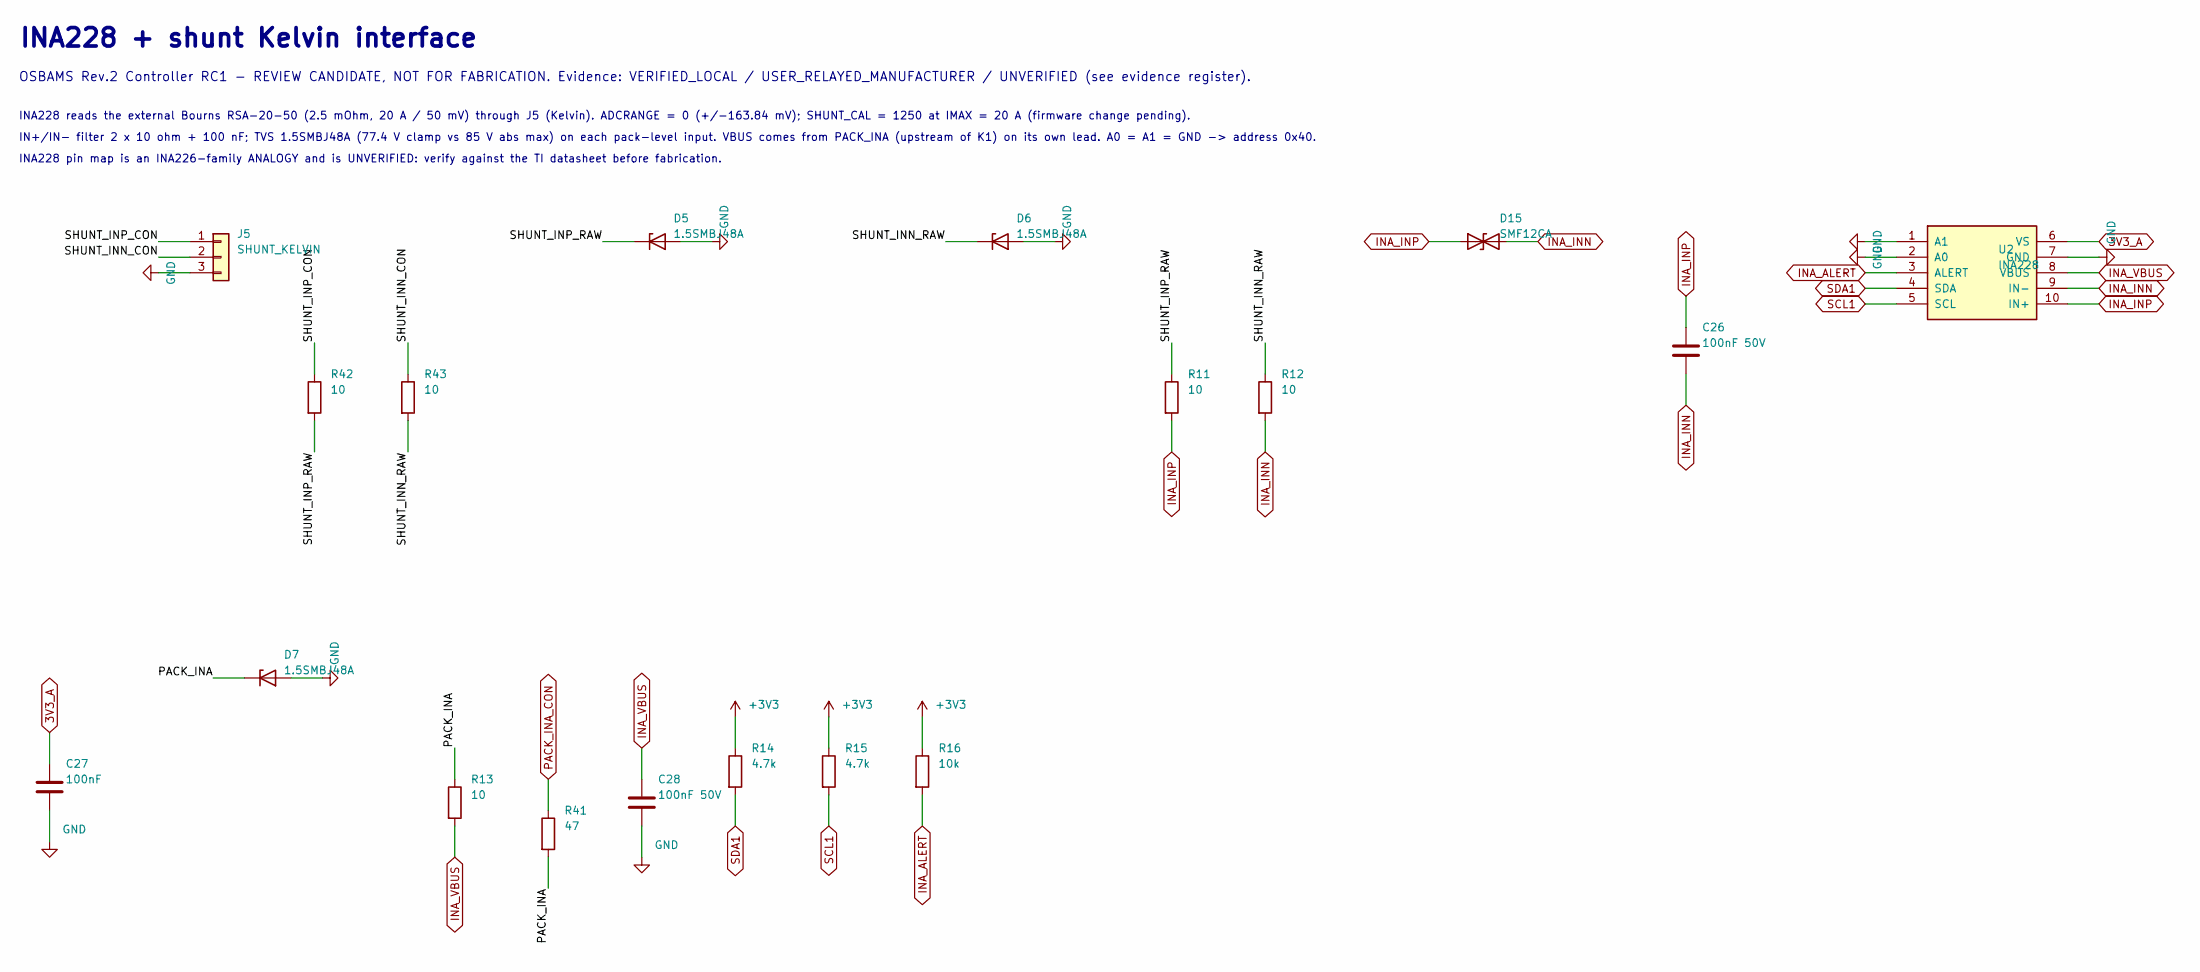
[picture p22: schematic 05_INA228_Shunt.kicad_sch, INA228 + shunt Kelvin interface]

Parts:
C26, C28: 100nF 50V; C_0603_1608Metric; MPN GRM188R71H104KA93D
C27: 100nF; C_0603_1608Metric; MPN GRM188R71H104KA93D
D5, D6, D7: 1.5SMBJ48A; D_SMB; MPN 1.5SMBJ48A
D15: SMF12CA; D_SMF; MPN SMF12CA
J5: SHUNT_KELVIN; Molex_KK-254_AE-6410-03A_1x03_P2.54mm_Vertical; MPN 22-27-2031
R11, R12, R13: 10; R_0603_1608Metric; MPN CRCW060310R0FKEA
R14, R15: 4.7k; R_0603_1608Metric; MPN CRCW06034K70FKEA
R16: 10k; R_0603_1608Metric; MPN CRCW060310K0FKEA
R41: 47; R_1206_3216Metric; MPN ERJ-P08F47R0V
R42, R43: 10; R_1206_3216Metric; MPN ERJ-P08F10R0V
U2: INA228; MSOP-10_3x3mm_P0.5mm; MPN INA228AIDGSR

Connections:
3V3_A: C27.1, U2.6 (VS); also elsewhere on the board
+3V3: R14.1, R15.1, R16.1; also elsewhere on the board
/05_INA228_Shunt/PACK_INA: D7.1 (K), R13.1, R41.2
/05_INA228_Shunt/SHUNT_INN_CON: J5.2, R43.1
/05_INA228_Shunt/SHUNT_INN_RAW: D6.1 (K), R12.1, R43.2
/05_INA228_Shunt/SHUNT_INP_CON: J5.1, R42.1
/05_INA228_Shunt/SHUNT_INP_RAW: D5.1 (K), R11.1, R42.2
GND: C27.2, C28.2, D5.2 (A), D6.2 (A), D7.2 (A), J5.3, U2.1 (A1), U2.2 (A0), U2.7 (GND); also elsewhere on the board
INA_ALERT: R16.2, U2.3 (ALERT); also elsewhere on the board
INA_INN: C26.2, D15.2 (A2), R12.2, U2.9 (IN-); also elsewhere on the board
INA_INP: C26.1, D15.1 (A1), R11.2, U2.10 (IN+); also elsewhere on the board
INA_VBUS: C28.1, R13.2, U2.8 (VBUS); also elsewhere on the board
PACK_INA_CON: R41.1; also elsewhere on the board
SCL1: R15.2, U2.5 (SCL); also elsewhere on the board
SDA1: R14.2, U2.4 (SDA); also elsewhere on the board

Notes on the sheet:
INA228 pin map is an INA226-family ANALOGY and is UNVERIFIED: verify against the TI datasheet before fabrication.
IN+/IN- filter 2 x 10 ohm + 100 nF; TVS 1.5SMBJ48A (77.4 V clamp vs 85 V abs max) on each pack-level input. VBUS comes from PACK_INA (upstream of K1) on its own lead. A0 = A1 = GND -> address 0x40.
OSBAMS Rev.2 Controller RC1 - REVIEW CANDIDATE, NOT FOR FABRICATION. Evidence: VERIFIED_LOCAL / USER_RELAYED_MANUFACTURER / UNVERIFIED (see evidence register).
INA228 + shunt Kelvin interface
INA228 reads the external Bourns RSA-20-50 (2.5 mOhm, 20 A / 50 mV) through J5 (Kelvin). ADCRANGE = 0 (+/-163.84 mV); SHUNT_CAL = 1250 at IMAX = 20 A (firmware change pending).

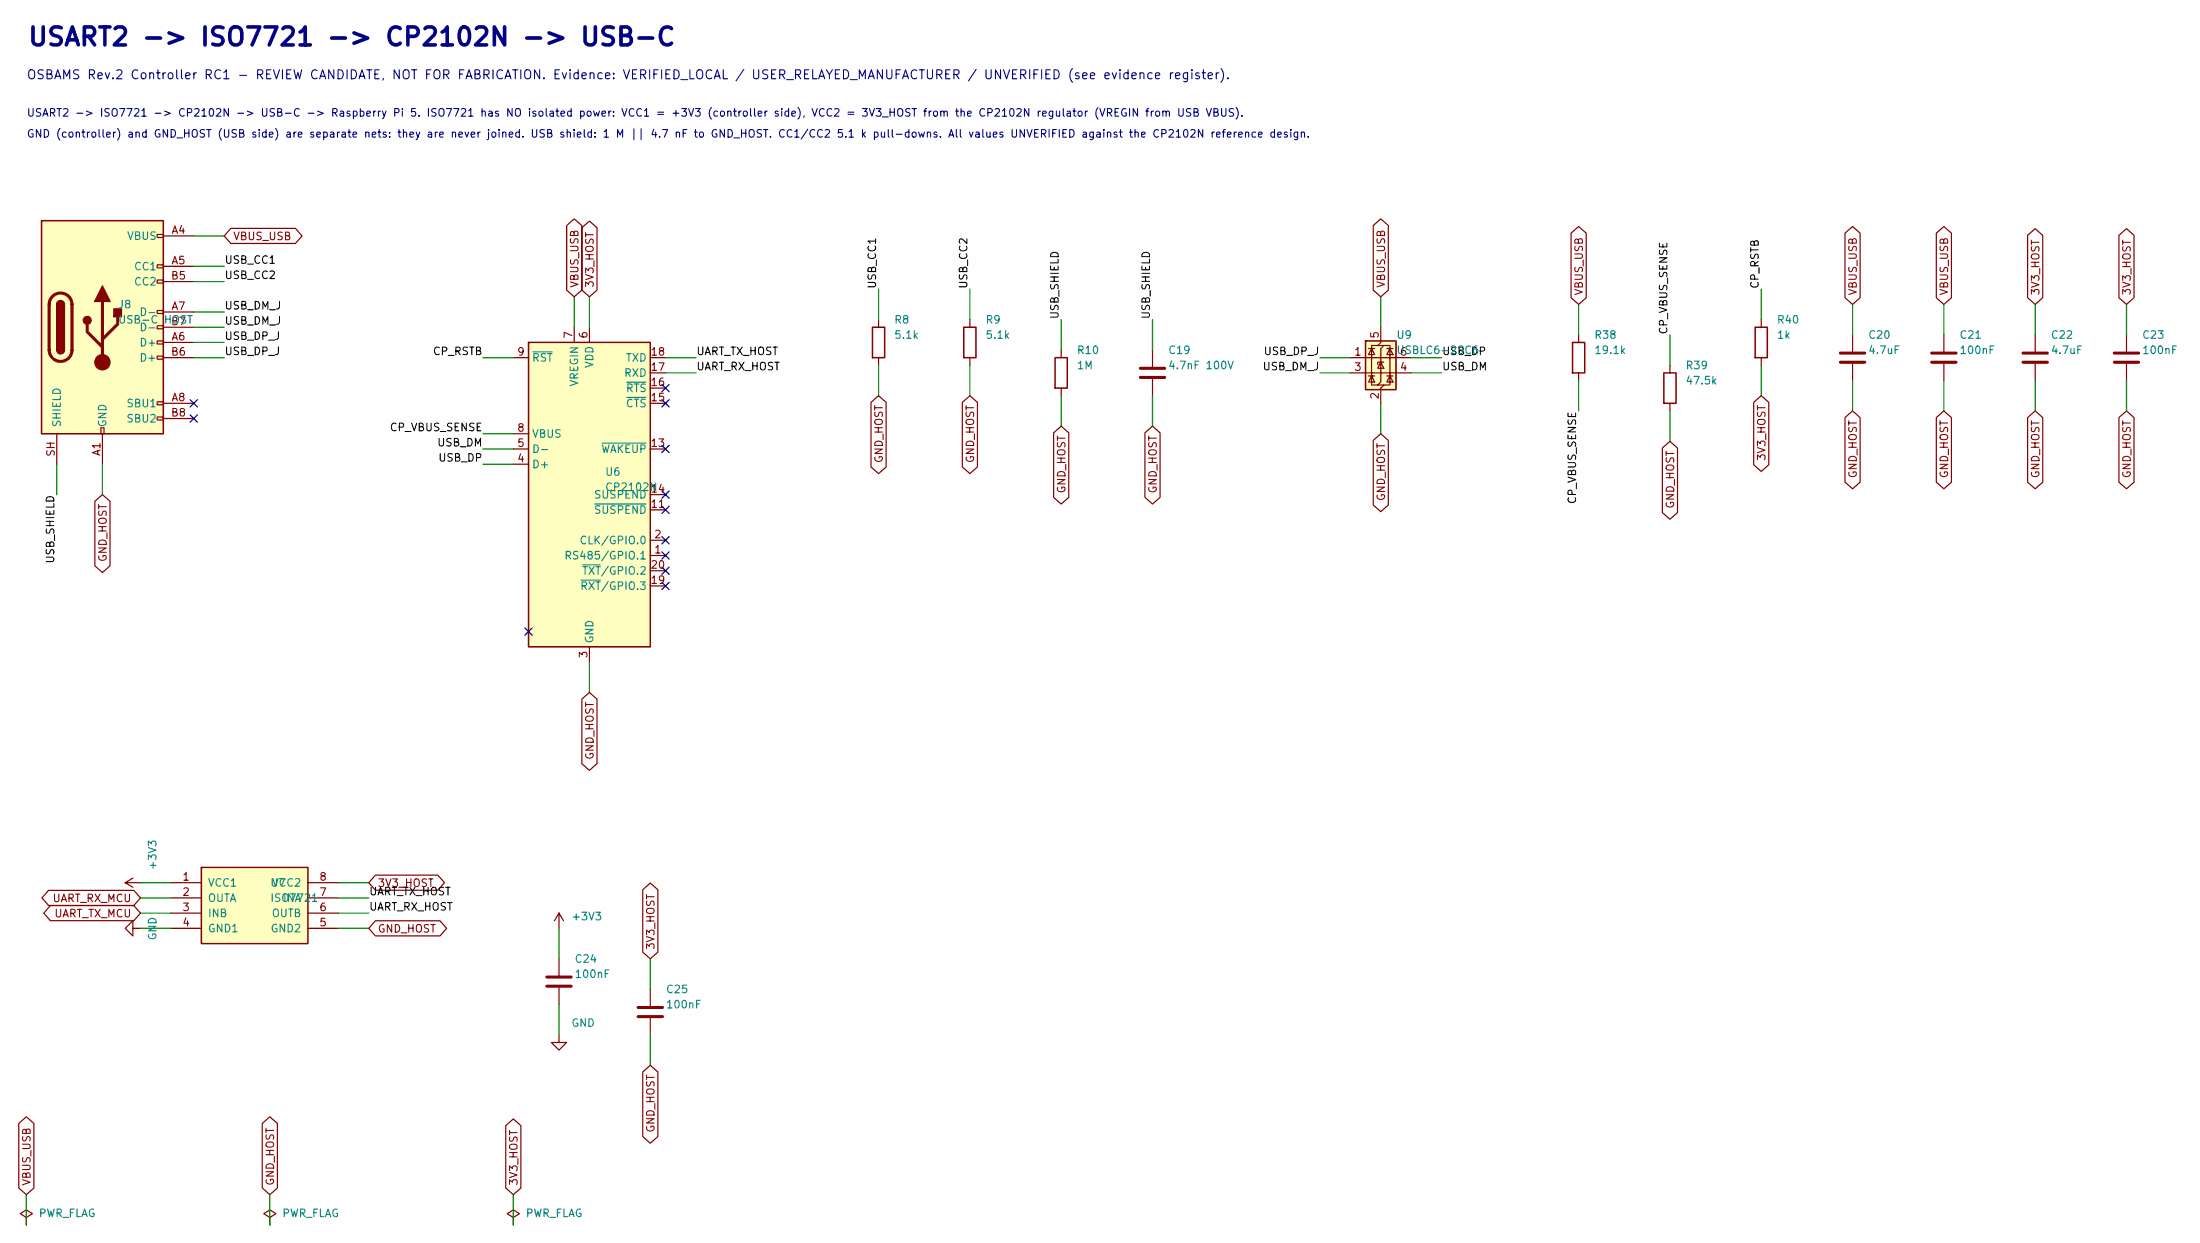
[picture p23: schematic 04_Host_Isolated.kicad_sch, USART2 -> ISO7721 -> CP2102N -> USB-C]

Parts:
C19: 4.7nF 100V; C_0805_2012Metric; MPN GRM21BR72A472KA01L
C20, C22: 4.7uF; C_0805_2012Metric; MPN GRM21BR61A475KA73L
C21, C23, C24, C25: 100nF; C_0603_1608Metric; MPN GRM188R71H104KA93D
J8: USB-C HOST; USB_C_Receptacle_GCT_USB4105-xx-A_16P_TopMnt_Horizontal; MPN USB4105-GF-A
R8, R9: 5.1k; R_0603_1608Metric; MPN CRCW06035K10FKEA
R10: 1M; R_0603_1608Metric; MPN CRCW06031M00FKEA
R38: 19.1k; R_0603_1608Metric; MPN CRCW060319K1FKEA
R39: 47.5k; R_0603_1608Metric; MPN CRCW060347K5FKEA
R40: 1k; R_0603_1608Metric; MPN CRCW06031K00FKEA
U6: CP2102N; SiliconLabs_QFN-20-1EP_3x3mm_P0.5mm_EP1.8x1.8mm; MPN CP2102N-A02-GQFN20
U7: ISO7721; SOIC-8_3.9x4.9mm_P1.27mm; MPN ISO7721DR
U9: USBLC6-2SC6; SOT-23-6; MPN USBLC6-2SC6

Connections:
3V3_HOST: C22.1, C23.1, C25.1, R40.2, U6.6 (VDD), U7.8 (VCC2); also elsewhere on the board
+3V3: C24.1, U7.1 (VCC1); also elsewhere on the board
/04_Host_Isolated/CP_RSTB: R40.1, U6.9 (~RST)
/04_Host_Isolated/CP_VBUS_SENSE: R38.2, R39.1, U6.8 (VBUS)
/04_Host_Isolated/UART_RX_HOST: U6.17 (RXD), U7.6 (OUTB)
/04_Host_Isolated/UART_TX_HOST: U6.18 (TXD), U7.7 (INA)
/04_Host_Isolated/USB_CC1: J8.A5 (CC1), R8.1
/04_Host_Isolated/USB_CC2: J8.B5 (CC2), R9.1
/04_Host_Isolated/USB_DM: U6.5 (D-), U9.4 (I/O2)
/04_Host_Isolated/USB_DM_J: J8.A7 (D-), J8.B7 (D-), U9.3 (I/O2)
/04_Host_Isolated/USB_DP: U6.4 (D+), U9.6 (I/O1)
/04_Host_Isolated/USB_DP_J: J8.A6 (D+), J8.B6 (D+), U9.1 (I/O1)
/04_Host_Isolated/USB_SHIELD: C19.1, J8.SH (SHIELD), R10.1
GND: C24.2, U7.4 (GND1); also elsewhere on the board
GND_HOST: C19.2, C20.2, C21.2, C22.2, C23.2, C25.2, J8.A1 (GND), J8.A12 (GND), J8.B1 (GND), J8.B12 (GND), R8.2, R9.2, R10.2, R39.2, U6.3 (GND), U6.12 (GND), U6.21 (GND), U7.5 (GND2), U9.2 (GND); also elsewhere on the board
UART_RX_MCU: U7.2 (OUTA); also elsewhere on the board
UART_TX_MCU: U7.3 (INB); also elsewhere on the board
VBUS_USB: C20.1, C21.1, J8.A4 (VBUS), J8.A9 (VBUS), J8.B4 (VBUS), J8.B9 (VBUS), R38.1, U6.7 (VREGIN), U9.5 (VBUS)

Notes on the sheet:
USART2 -> ISO7721 -> CP2102N -> USB-C -> Raspberry Pi 5. ISO7721 has NO isolated power: VCC1 = +3V3 (controller side), VCC2 = 3V3_HOST from the CP2102N regulator (VREGIN from USB VBUS).
GND (controller) and GND_HOST (USB side) are separate nets: they are never joined. USB shield: 1 M || 4.7 nF to GND_HOST. CC1/CC2 5.1 k pull-downs. All values UNVERIFIED against the CP2102N reference design.
OSBAMS Rev.2 Controller RC1 - REVIEW CANDIDATE, NOT FOR FABRICATION. Evidence: VERIFIED_LOCAL / USER_RELAYED_MANUFACTURER / UNVERIFIED (see evidence register).
USART2 -> ISO7721 -> CP2102N -> USB-C

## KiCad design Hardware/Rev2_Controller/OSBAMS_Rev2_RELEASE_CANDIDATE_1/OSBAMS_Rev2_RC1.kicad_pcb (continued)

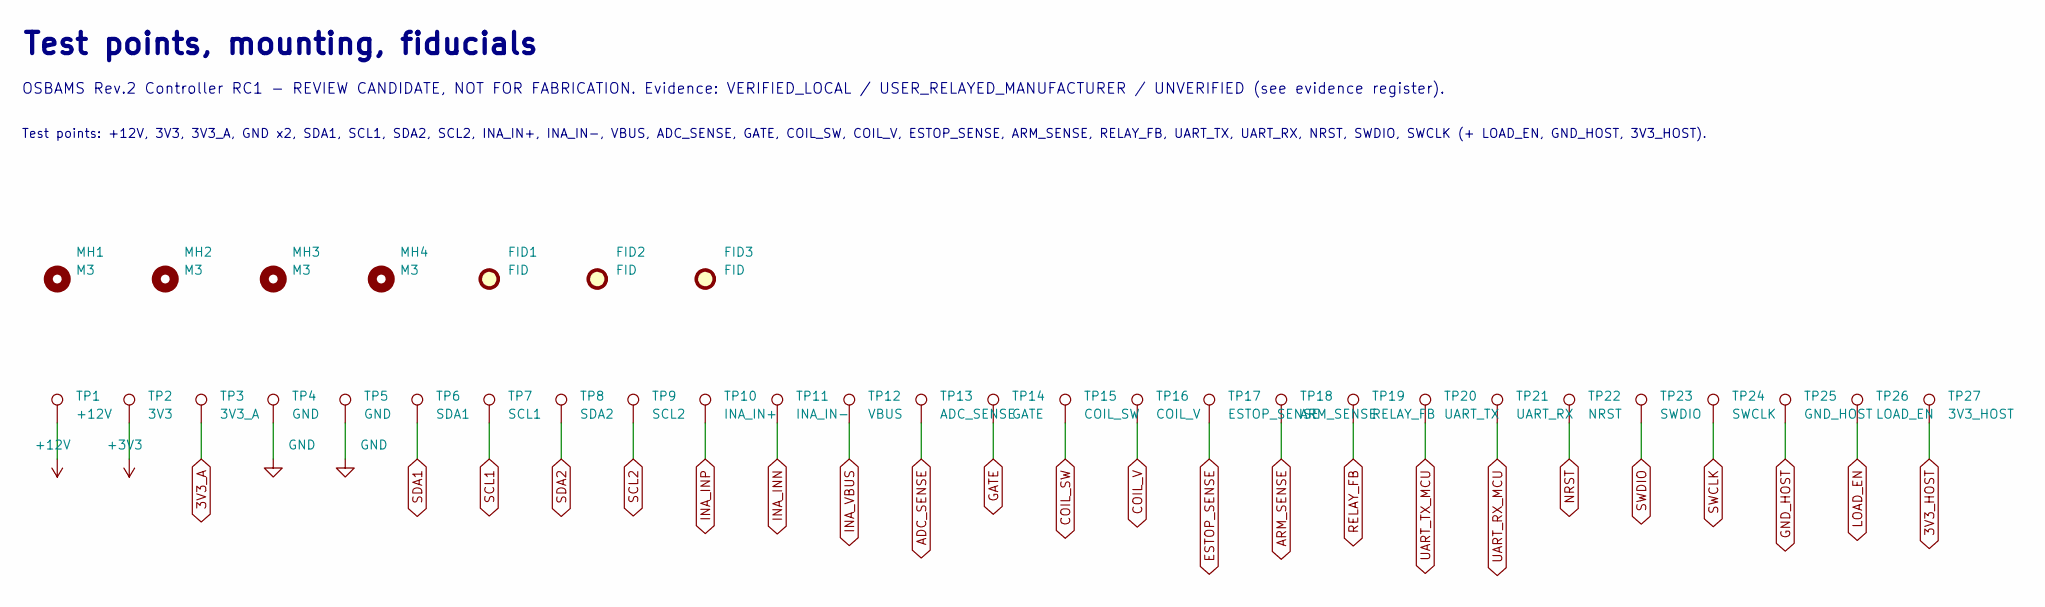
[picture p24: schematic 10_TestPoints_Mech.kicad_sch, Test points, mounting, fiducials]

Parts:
FID1, FID2, FID3: FID; Fiducial_1mm_Mask2mm; MPN (PCB feature)
MH1, MH2, MH3, MH4: M3; MountingHole_3.2mm_M3; MPN (PCB feature)
TP1: +12V; TestPoint_Pad_D1.5mm; MPN (PCB feature)
TP2: 3V3; TestPoint_Pad_D1.5mm; MPN (PCB feature)
TP3: 3V3_A; TestPoint_Pad_D1.5mm; MPN (PCB feature)
TP4, TP5: GND; TestPoint_Pad_D1.5mm; MPN (PCB feature)
TP6: SDA1; TestPoint_Pad_D1.5mm; MPN (PCB feature)
TP7: SCL1; TestPoint_Pad_D1.5mm; MPN (PCB feature)
TP8: SDA2; TestPoint_Pad_D1.5mm; MPN (PCB feature)
TP9: SCL2; TestPoint_Pad_D1.5mm; MPN (PCB feature)
TP10: INA_IN+; TestPoint_Pad_D1.5mm; MPN (PCB feature)
TP11: INA_IN-; TestPoint_Pad_D1.5mm; MPN (PCB feature)
TP12: VBUS; TestPoint_Pad_D1.5mm; MPN (PCB feature)
TP13: ADC_SENSE; TestPoint_Pad_D1.5mm; MPN (PCB feature)
TP14: GATE; TestPoint_Pad_D1.5mm; MPN (PCB feature)
TP15: COIL_SW; TestPoint_Pad_D1.5mm; MPN (PCB feature)
TP16: COIL_V; TestPoint_Pad_D1.5mm; MPN (PCB feature)
TP17: ESTOP_SENSE; TestPoint_Pad_D1.5mm; MPN (PCB feature)
TP18: ARM_SENSE; TestPoint_Pad_D1.5mm; MPN (PCB feature)
TP19: RELAY_FB; TestPoint_Pad_D1.5mm; MPN (PCB feature)
TP20: UART_TX; TestPoint_Pad_D1.5mm; MPN (PCB feature)
TP21: UART_RX; TestPoint_Pad_D1.5mm; MPN (PCB feature)
TP22: NRST; TestPoint_Pad_D1.5mm; MPN (PCB feature)
TP23: SWDIO; TestPoint_Pad_D1.5mm; MPN (PCB feature)
TP24: SWCLK; TestPoint_Pad_D1.5mm; MPN (PCB feature)
TP25: GND_HOST; TestPoint_Pad_D1.5mm; MPN (PCB feature)
TP26: LOAD_EN; TestPoint_Pad_D1.5mm; MPN (PCB feature)
TP27: 3V3_HOST; TestPoint_Pad_D1.5mm; MPN (PCB feature)

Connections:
3V3_A: TP3.1; also elsewhere on the board
3V3_HOST: TP27.1; also elsewhere on the board
+3V3: TP2.1; also elsewhere on the board
+12V: TP1.1; also elsewhere on the board
ADC_SENSE: TP13.1; also elsewhere on the board
ARM_SENSE: TP18.1; also elsewhere on the board
COIL_SW: TP15.1; also elsewhere on the board
COIL_V: TP16.1; also elsewhere on the board
ESTOP_SENSE: TP17.1; also elsewhere on the board
GATE: TP14.1; also elsewhere on the board
GND: TP4.1, TP5.1; also elsewhere on the board
GND_HOST: TP25.1; also elsewhere on the board
INA_INN: TP11.1; also elsewhere on the board
INA_INP: TP10.1; also elsewhere on the board
INA_VBUS: TP12.1; also elsewhere on the board
LOAD_EN: TP26.1; also elsewhere on the board
NRST: TP22.1; also elsewhere on the board
RELAY_FB: TP19.1; also elsewhere on the board
SCL1: TP7.1; also elsewhere on the board
SCL2: TP9.1; also elsewhere on the board
SDA1: TP6.1; also elsewhere on the board
SDA2: TP8.1; also elsewhere on the board
SWCLK: TP24.1; also elsewhere on the board
SWDIO: TP23.1; also elsewhere on the board
UART_RX_MCU: TP21.1; also elsewhere on the board
UART_TX_MCU: TP20.1; also elsewhere on the board

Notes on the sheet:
OSBAMS Rev.2 Controller RC1 - REVIEW CANDIDATE, NOT FOR FABRICATION. Evidence: VERIFIED_LOCAL / USER_RELAYED_MANUFACTURER / UNVERIFIED (see evidence register).
Test points, mounting, fiducials
Test points: +12V, 3V3, 3V3_A, GND x2, SDA1, SCL1, SDA2, SCL2, INA_IN+, INA_IN-, VBUS, ADC_SENSE, GATE, COIL_SW, COIL_V, ESTOP_SENSE, ARM_SENSE, RELAY_FB, UART_TX, UART_RX, NRST, SWDIO, SWCLK (+ LOAD_EN, GND_HOST, 3V3_HOST).


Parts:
D9: S1M; D_SMA; MPN S1M-13-F
D10: COIL ON; LED_0805_2012Metric; MPN 150080AS75000
J2: ESTOP; EB21A-02-C; MPN EB21A-02-C
J3: ARM; EB21A-02-C; MPN EB21A-02-C
J4: K1_COIL; EB21A-02-C; MPN EB21A-02-C
Q1: IRLML0060; SOT-23; MPN IRLML0060TRPBF
R21: 220; R_0603_1608Metric; MPN CRCW0603220RFKEA
R22: 10k; R_0603_1608Metric; MPN CRCW060310K0FKEA
R23: 2.2k; R_0603_1608Metric; MPN CRCW06032K20FKEA

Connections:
+12V: J2.1; also elsewhere on the board
/07_Coil_Driver/LED_COIL: D10.2 (A), R23.2
COIL_SW: D9.2 (A), D10.1 (K), J4.2, Q1.3 (D); also elsewhere on the board
COIL_V: D9.1 (K), J3.2, J4.1, R23.1; also elsewhere on the board
ESTOP_OUT: J2.2, J3.1; also elsewhere on the board
GATE: Q1.1 (G), R21.2, R22.1; also elsewhere on the board
GND: Q1.2 (S), R22.2; also elsewhere on the board
LOAD_EN: R21.1; also elsewhere on the board

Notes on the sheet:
E-stop / ARM / K1 coil chain and MOSFET driver
Coil chain: +12V -> J2 E-stop (Eaton M22-PV-K02 NC) -> J3 ARM (C&K T102SHZQE) -> J4 K1 coil -> Q1 -> GND. E-stop and ARM physically open the coil supply; firmware cannot bypass either.
OSBAMS Rev.2 Controller RC1 - REVIEW CANDIDATE, NOT FOR FABRICATION. Evidence: VERIFIED_LOCAL / USER_RELAYED_MANUFACTURER / UNVERIFIED (see evidence register).
Q1 gate: 220 ohm series, 10k pull-down (default OFF). Flyback D9 cathode on the +12 V side. No fast-release TVS in RC1. Battery discharge current never flows through this board.

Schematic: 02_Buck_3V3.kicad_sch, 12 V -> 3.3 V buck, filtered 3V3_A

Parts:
C2: 10uF 50V; C_1210_3225Metric; MPN GRM32ER71H106KA12L
C3, C8: 100nF; C_0603_1608Metric; MPN GRM188R71H104KA93D
C4: 100nF (bootstrap); C_0603_1608Metric; MPN GRM188R71H104KA93D
C5, C6: 22uF; C_0805_2012Metric; MPN GRM21BR61A226ME44L
C7: 4.7uF; C_0805_2012Metric; MPN GRM21BR61A475KA73L
D3: 3V3 ON; LED_0805_2012Metric; MPN 150080GS75000
FB1: 600R@100MHz; L_0603_1608Metric; MPN BLM18PG601SN1D
L1: 10uH; L_Bourns_SRN6045TA; MPN SRN6045TA-100M
R1: 33.2k; R_0603_1608Metric; MPN CRCW060333K2FKEA
R2: 10k; R_0603_1608Metric; MPN CRCW060310K0FKEA
R3: 100k; R_0603_1608Metric; MPN CRCW0603100KFKEA
R4: 3.3k; R_0603_1608Metric; MPN CRCW06033K30FKEA
R5: 1k; R_0603_1608Metric; MPN CRCW06031K00FKEA
U3: LMR14006Y; SOT-23-6; MPN LMR14006YDDCR

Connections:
3V3_A: C7.1, C8.1, FB1.2, R4.1; also elsewhere on the board
+3V3: C5.1, C6.1, FB1.1, L1.2, R1.1, R5.1; also elsewhere on the board
+12V: C2.1, C3.1, R3.1, U3.5 (VIN); also elsewhere on the board
/02_Buck_3V3/BUCK_CB: C4.1, U3.1 (CB)
/02_Buck_3V3/BUCK_EN: R3.2, U3.4 (EN)
/02_Buck_3V3/BUCK_FB: R1.2, R2.1, U3.3 (FB)
/02_Buck_3V3/BUCK_SW: C4.2, L1.1, U3.6 (SW)
/02_Buck_3V3/LED_3V3: D3.2 (A), R5.2
GND: C2.2, C3.2, C5.2, C6.2, C7.2, C8.2, D3.1 (K), R2.2, R4.2, U3.2 (GND); also elsewhere on the board

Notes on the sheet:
LMR14006Y (4-40 V, 600 mA, 2.1 MHz, VREF 0.765 V: user-relayed). Vout = 0.765 x (1 + R1/R2) = 0.765 x (1 + 33.2k/10k) = 3.305 V.
12 V -> 3.3 V buck, filtered 3V3_A
OSBAMS Rev.2 Controller RC1 - REVIEW CANDIDATE, NOT FOR FABRICATION. Evidence: VERIFIED_LOCAL / USER_RELAYED_MANUFACTURER / UNVERIFIED (see evidence register).
R4 3.3k: permanent bleeder on 3V3_A; limits the rail to < 1 V if PACK+ back-feeds the MCU pin while the board is unpowered (calculations section 1.1).
Hot loop: C2/C3 - U3 VIN/GND - SW - L1 kept tiny in layout. No 5 V rail. 3V3_A = 3V3 through ferrite FB1 + 4.7 uF + 100 nF (VDDA, INA228).

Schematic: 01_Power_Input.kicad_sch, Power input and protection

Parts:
C1: 10uF 50V; C_1210_3225Metric; MPN GRM32ER71H106KA12L
D1: SMBJ15A; D_SMB; MPN SMBJ15A
D2: SS14; D_SMA; MPN SS14-E3/61T
F1: 1A fast; Fuse_1206_3216Metric; MPN 0453001.MR
J1: 12V_IN; EB21A-02-C; MPN EB21A-02-C

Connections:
+12V: C1.1, D1.1 (K), D2.1 (K); also elsewhere on the board
/01_Power_Input/12V_F: D2.2 (A), F1.2
/01_Power_Input/12V_RAW: F1.1, J1.1
GND: C1.2, D1.2 (A), J1.2; also elsewhere on the board

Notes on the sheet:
Diode polarity: Device:D / D_Schottky / D_Zener pin 1 = cathode (K); KiCad SMA/SMB footprints pad 1 = cathode - verified by tools in checks.py (netlist polarity check).
OSBAMS Rev.2 Controller RC1 - REVIEW CANDIDATE, NOT FOR FABRICATION. Evidence: VERIFIED_LOCAL / USER_RELAYED_MANUFACTURER / UNVERIFIED (see evidence register).
Power input and protection
J1: 12 V control input (XDR-75-12 set and verified at 12.0 V). F1 1 A fast, D2 Schottky reverse-polarity block (0.4 V drop), TVS D1 SMBJ15A across +12V AFTER D2 (reverse polarity is blocked, not clamped).

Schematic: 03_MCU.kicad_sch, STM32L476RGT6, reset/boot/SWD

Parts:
C10, C11, C12, C13, C14, C17, C18: 100nF; C_0603_1608Metric; MPN GRM188R71H104KA93D
C15: 4.7uF; C_0805_2012Metric; MPN GRM21BR61A475KA73L
C16: 1uF; C_0805_2012Metric; MPN GRM21BR71C105KA01L
D4: HEARTBEAT; LED_0805_2012Metric; MPN 150080GS75000
J9: SWD; FTSH-105-01-L-DV-K; MPN FTSH-105-01-L-DV-K
JP1: BOOT0; PinHeader_1x02_P2.54mm_Vertical; MPN TSW-102-07-G-S
R6: 10k; R_0603_1608Metric; MPN CRCW060310K0FKEA
R7: 1k; R_0603_1608Metric; MPN CRCW06031K00FKEA
SW1: RESET; SW_SPST_PTS810; MPN PTS810SJM250SMTRLFS
U1: STM32L476RGT6; LQFP-64_10x10mm_P0.5mm; MPN STM32L476RGT6

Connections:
3V3_A: C16.1, C17.1, U1.13 (VDDA); also elsewhere on the board
+3V3: C10.1, C11.1, C12.1, C13.1, C14.1, C15.1, J9.1 (VTref), JP1.1, U1.1 (VBAT), U1.19 (VDD), U1.32 (VDD), U1.48 (VDDUSB), U1.64 (VDD); also elsewhere on the board
/03_MCU/BOOT0: JP1.2, R6.1, U1.60 (BOOT0)
/03_MCU/LED_HB: D4.2 (A), R7.2
/03_MCU/LED_HB_PIN: R7.1, U1.21 (PA5)
/03_MCU/SWO: J9.6 (SWO/TDO), U1.55 (PB3)
ADC_SENSE: U1.15 (PA1); also elsewhere on the board
ARM_SENSE: U1.51 (PC10); also elsewhere on the board
ESTOP_SENSE: U1.14 (PA0); also elsewhere on the board
GND: C10.2, C11.2, C12.2, C13.2, C14.2, C15.2, C16.2, C17.2, C18.2, D4.1 (K), J9.3 (GND), J9.5 (GND), J9.9 (GNDDetect), R6.2, SW1.2, U1.12 (VSSA), U1.18 (VSS), U1.31 (VSS), U1.47 (VSS), U1.63 (VSS); also elsewhere on the board
INA_ALERT: U1.26 (PB0); also elsewhere on the board
LOAD_EN: U1.39 (PC8); also elsewhere on the board
NRST: C18.1, J9.10 (~RESET), SW1.1, U1.7 (NRST); also elsewhere on the board
RELAY_FB: U1.40 (PC9); also elsewhere on the board
SCL1: U1.61 (PB8); also elsewhere on the board
SCL2: U1.29 (PB10); also elsewhere on the board
SDA1: U1.62 (PB9); also elsewhere on the board
SDA2: U1.30 (PB11); also elsewhere on the board
SWCLK: J9.4 (SWCLK/TCK), U1.49 (PA14); also elsewhere on the board
SWDIO: J9.2 (SWDIO/TMS), U1.46 (PA13); also elsewhere on the board
UART_RX_MCU: U1.17 (PA3); also elsewhere on the board
UART_TX_MCU: U1.16 (PA2); also elsewhere on the board

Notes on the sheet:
STM32L476RGT6 direct. HSI16 -> PLL 80 MHz (no crystal), no LSE, USB unused. PA0 ESTOP_SENSE (LOW = healthy), PC9 RELAY_FB (active low), PC10 ARM_SENSE (HIGH = armed, status only).
PA1 ADC_SENSE (VREFINT-corrected), PA2/PA3 USART2, PB8/PB9 I2C1 (INA228), PB10/PB11 I2C2 (TC74, <= 100 kHz), PB0 INA228 ALERT, PC8 LOAD_EN (default low), PA5 heartbeat, SWD on J9.
STM32L476RGT6, reset/boot/SWD
Unused pins carry no-connect flags and are configured analog/pulled low in firmware. BOOT0: 10k pull-down + jumper JP1 to 3V3 (ROM bootloader).
OSBAMS Rev.2 Controller RC1 - REVIEW CANDIDATE, NOT FOR FABRICATION. Evidence: VERIFIED_LOCAL / USER_RELAYED_MANUFACTURER / UNVERIFIED (see evidence register).


Board: 4 copper layers, 100.0 x 90.0 mm, 149 parts (0 on the bottom side), 72 nets.

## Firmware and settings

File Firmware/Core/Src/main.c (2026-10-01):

/*
 * main.c — OSBAMS Firmware v4 (recoverable safety states)
 *
 * Layered flow (unchanged):
 *     main.c → Measurement Engine → Sensor Manager → I2C / INA228 / TC74
 *
 * WHAT CHANGED vs v3 (frozen decisions, see DESIGN_DECISIONS.md):
 *
 * 1. Fault() is no longer a while(1) dead end. A fault now: forces the
 *    load off via Load_EmergencyDisable(), transitions the controller to
 *    TEST_FAULT, reports over serial — and RETURNS. The main loop keeps
 *    running so it can stream telemetry, watch the E-stop, and accept the
 *    operator ACK. Recovery: ACK -> SELF_TEST -> re-run checks -> IDLE.
 *    A power cycle is only needed for catastrophic failures (watchdog
 *    reset, corrupt config), never for an ordinary operating fault.
 *
 * 2. E-stop (PA0, estop.c) polled every loop. Trip -> Load_EmergencyDisable()
 *    + TEST_ESTOP (distinct from FAULT). The PA0 path is MONITORING; the
 *    physical NC contact already cut the contactor coil in hardware.
 *
 * 3. Contactor supervision (PC9 via load_driver.c): "commanded OFF but
 *    AUX says ON" is checked every loop while not running — that is the
 *    welded-contactor case and is an immediate fault.
 *
 * 4. Operator ACK arrives over UART as the line "ACK". The ACK is GATED:
 *    ignored unless the controller is in TEST_FAULT or TEST_ESTOP, and
 *    for TEST_ESTOP additionally ignored until Estop_IsHealthy() (the
 *    mushroom is physically reset). On accepted ACK: Safety_Acknowledge(),
 *    controller -> SELF_TEST, checks re-run, PRECHECK_PASS or re-fault.
 *
 * 5. Single tick source: tick.c. SysTick_Handler calls Tick_OnSysTick()
 *    only; the local g_tick_ms is gone.
 *
 * INTEGRATION NOTES (for merging into the real tree):
 *  - Requires the FIXED ina228.c/h (SHUNT_CAL /1e10 + freshness flag) and
 *    the FIXED load_driver.c (PC9 enabled, tick-based timeouts) — the
 *    2026-08 uploads still contained the old versions of both.
 *  - sensor_manager.c must update its call:
 *        INA228_ReadCurrent_mA(&raw32)  ->  INA228_ReadCurrent_mA(&raw32, NULL)
 *    (or pass a real freshness flag once the safety layer consumes it).
 *  - uart.h needs the UART2_TryReadByte() prototype (uart_rx_addition.c).
 */

#include "stm32l476xx.h"
#include "app_config.h"
#include "system_clock.h"
#include "osbams_status.h"
#include "sensor_manager.h"
#include "measurement.h"
#include "safety.h"
#include "test_controller.h"
#include "uart.h"
#include "protocol.h"
#include "acquisition_timer.h"
#include "watchdog.h"
#include "adc_safety.h"
#include "load_driver.h"
#include "estop.h"
#include "tick.h"
#include <stdio.h>
#include <string.h>
#include <stdint.h>

/* dev3: this hardware/firmware synchronization pass -- POWER decode fix,
 * TC74 address, Durakool feedback correction, ADC channel config, fresh-
 * sample fault recovery, and the other fixes in this revision. Still a
 * single literal here rather than a shared version header — test_protocol_c.c
 * separately hardcodes "0.9.0-dev1" as a fixed TEST INPUT for exercising
 * the encoder (not a claim about the current firmware version), so that's
 * expected to differ and isn't a bug — but if this project grows a real
 * multi-file version story, centralize both behind one header. */
#define OSBAMS_FW_VERSION_STR  "0.9.0-dev3"

/* ── Globals ─────────────────────────────────────────────────────── */
static sensor_manager_t      g_sensors;
static measurement_context_t g_measure;
static safety_context_t      g_safety;

/* FIX: was a local `test_start_ms` in main()'s loop, set ONCE at boot and
 * never touched again -- so OSBAMS_MAX_TEST_DURATION_S measured "time
 * since boot", not "time since the current test started". A fixture
 * sitting in IDLE long enough could raise FAULT_MAX_DURATION with no
 * test running. Promoted to file scope so PollOperatorCommand()'s fresh
 * Safety_Evaluate() can read it too, and reset on the transition INTO
 * TEST_DISCHARGING (see the main loop) rather than only at boot. */
static uint32_t g_test_start_ms = 0;

static const safety_limits_t g_limits = {
    .max_temp_c10   = OSBAMS_DEFAULT_MAX_TEMP_C10,
    .min_voltage_mv = OSBAMS_DEFAULT_MIN_VOLTAGE_MV,
    .max_voltage_mv = OSBAMS_DEFAULT_MAX_VOLTAGE_MV,
    .max_current_ma = OSBAMS_DEFAULT_MAX_CURRENT_MA,
    .max_duration_s = OSBAMS_MAX_TEST_DURATION_S,
};

/* ── SysTick: sole increment site for the one tick counter ───────── */
void SysTick_Handler(void) { Tick_OnSysTick(); }
void TIM6_DAC_IRQHandler(void) { AcquisitionTimer_OnUpdate(); }

static void SysTick_Init(void) { SysTick_Config(SYSTICK_RELOAD); }

static void delay_ms(uint32_t ms)
{
    uint32_t start = Tick_GetMs();
    while (Tick_ElapsedMs(start) < ms);
}

/* ── LED ─────────────────────────────────────────────────────────── */
static void LED_Init(void)
{
    RCC->AHB2ENR |= RCC_AHB2ENR_GPIOAEN;
    GPIOA->MODER &= ~GPIO_MODER_MODE5;
    GPIOA->MODER |=  GPIO_MODER_MODE5_0;
}
static void LED_On(void)  { GPIOA->ODR |=  (1u << 5); }
static void LED_Off(void) { GPIOA->ODR &= ~(1u << 5); }

/* ── Fault handling: latch, disable, report, RETURN ──────────────── */
static void Fault(const char *reason)
{
    /* Hardware first: force the enable pin low with no waiting. The
     * confirming Load_Disable() check runs in the supervision below. */
    Load_EmergencyDisable();

    TestController_ProcessEvent(TEST_EVT_FAULT);

    char buf[80];
    size_t n = Protocol_EncodeFault(buf, sizeof(buf), reason);
    if (n) UART2_SendBytes((const uint8_t *)buf, (uint16_t)n);
    /* No while(1). The loop continues: telemetry, E-stop watch, ACK. */
}

static void EnterEstop(void)
{
    Load_EmergencyDisable();
    TestController_ProcessEvent(TEST_EVT_ESTOP);
    char buf[64];
    size_t n = Protocol_EncodeState(buf, sizeof(buf), TEST_ESTOP);
    if (n) UART2_SendBytes((const uint8_t *)buf, (uint16_t)n);
}

/* ── Boot / recovery self-test (shared by both paths) ────────────── */
/* Returns true if every startup requirement from the frozen design holds:
 * E-stop healthy, electrical + temperature channels ONLINE (via the Sensor
 * Manager — main.c names no chips, per the layering rule), contactor
 * confirmed open, no latched fault. Called at boot AND after every ACK. */
static bool RunSelfChecks(void)
{
    Estop_Poll();
    if (!Estop_IsHealthy())               return false;

    /* Chip-level probing stays inside the Sensor Manager; main.c only
     * asks for channel health. A recovery attempt first gives an OFFLINE
     * channel its chance to come back before we judge it. */
    SensorManager_AttemptRecovery(&g_sensors);
    if (SensorManager_GetHealth(&g_sensors, SENSOR_CH_BUS_VOLTAGE)
            != SENSOR_HEALTH_ONLINE)      return false;
    if (SensorManager_GetHealth(&g_sensors, SENSOR_CH_CURRENT)
            != SENSOR_HEALTH_ONLINE)      return false;
    if (SensorManager_GetHealth(&g_sensors, SENSOR_CH_TEMP_PACK)
            != SENSOR_HEALTH_ONLINE)      return false;

    /* Contactor: LOAD_FEEDBACK_PRESENT is now 1 (FROZEN) -- PC9 carries
     * real, definitive K1 feedback via the VO610A optocoupler, active
     * low. Load_Disable() here returns LOAD_STUCK if PC9 still reads
     * "closed" after commanding the pin low -- a genuinely welded
     * contactor, confirmed by actual HV presence downstream, not just
     * an inference. This is now a real, meaningful self-test gate. */
    if (Load_IsEnabled())                 return false;
    if (Load_Disable() == OSBAMS_STATUS_LOAD_STUCK) return false;

    if (g_safety.fault_latched)           return false;

    return true;
}

/* ── Operator command input: reads "ACK" line, gated by state ────── */
/*
 * FIX: previously called Safety_Acknowledge() (clearing the latch)
 * BEFORE RunSelfChecks(), and RunSelfChecks() only checks sensor HEALTH
 * (is the chip answering?) and Estop/contactor STATE — it never
 * re-evaluates actual voltage/current/temperature against thresholds.
 * A persistent condition (e.g. a pack still sitting at 45 V) would clear
 * the latch, pass the health checks, reach IDLE, and only re-fault on
 * the NEXT periodic acquisition — a window where the system reports IDLE
 * while still genuinely out of limits.
 *
 * Fixed order: keep the OLD fault latched through SELF_TEST, acquire a
 * FRESH sample, run Safety_Evaluate() against it, and only clear the old
 * latch + proceed to IDLE if that fresh evaluation itself reports
 * FAULT_NONE. If it doesn't, Safety_Evaluate() has already re-latched
 * the (possibly new) fault, and Fault() is called again — the state
 * never leaves FAULT/E_STOP on a still-bad reading.
 */
static void PollOperatorCommand(void)
{
    static char    cmd[16];
    static uint8_t cmd_len = 0;

    uint8_t b;
    while (UART2_TryReadByte(&b)) {
        if (b == '\n' || b == '\r') {
            cmd[cmd_len] = '\0';
            uint8_t had = cmd_len;
            cmd_len = 0;
            if (had == 0) continue;

            if (strcmp(cmd, "ACK") == 0) {
                test_state_t st = TestController_GetState();
                if (st != TEST_FAULT && st != TEST_ESTOP) continue;

                /* E-stop ACK gate: mushroom must be physically reset. */
                Estop_Poll();
                if (st == TEST_ESTOP && !Estop_IsHealthy()) {
                    UART2_SendString("OSBAMS,NACK,ESTOP_STILL_TRIPPED\r\n");
                    continue;
                }

                /* Old latch stays SET through this — do NOT acknowledge yet. */
                TestController_ProcessEvent(TEST_EVT_ACK_FAULT); /* -> SELF_TEST */

                bool checks_ok = RunSelfChecks();
                bool sample_ok = false;

                if (checks_ok) {
                    /* Fresh sample, fresh evaluation — this is the check
                     * that was missing before. */
                    uint64_t ts_us = (uint64_t)Tick_GetMs() * 1000ULL;
                    Measurement_Acquire(&g_measure, ts_us);
                    uint32_t elapsed_s = Tick_ElapsedMs(g_test_start_ms) / 1000;
                    fault_code_t f = Safety_Evaluate(&g_safety, &g_limits,
                                                     &g_measure.latest, elapsed_s);
                    sample_ok = (f == FAULT_NONE);
                }

                if (checks_ok && sample_ok) {
                    /* Only NOW clear the old latch — proven safe on a
                     * sample acquired after the ACK, not on stale state. */
                    Safety_Acknowledge(&g_safety);
                    TestController_ProcessEvent(TEST_EVT_PRECHECK_PASS);
                    char sb[64];
                    size_t n = Protocol_EncodeState(sb, sizeof(sb), TEST_IDLE);
                    if (n) UART2_SendBytes((const uint8_t *)sb, (uint16_t)n);
                } else {
                    /* checks_ok==false: RunSelfChecks() failed (sensor/
                     * estop/contactor). sample_ok==false: fresh evaluation
                     * still found a fault (already re-latched by
                     * Safety_Evaluate() above, if that's the branch taken).
                     * Either way: re-fault, stay latched, no path to IDLE. */
                    Fault("SELFTEST_RECHECK");
                }
            }
            /* Unknown commands ignored in v1; command set grows via
             * protocol.c, not ad-hoc strings here. */
        } else if (cmd_len < sizeof(cmd) - 1) {
            cmd[cmd_len++] = (char)b;
        } else {
            cmd_len = 0;   /* overlong line: discard */
        }
    }
}

/* ── Report sensor health at boot ────────────────────────────────── */
static void ReportSensorHealth(void)
{
    char buf[96];
    for (int ch = 0; ch < SENSOR_CH_COUNT; ch++) {
        sensor_health_t h = SensorManager_GetHealth(&g_sensors,
                                                     (sensor_channel_t)ch);
        snprintf(buf, sizeof(buf), "OSBAMS,SENSOR,%s,%s\r\n",
                 SensorManager_ChannelName((sensor_channel_t)ch),
                 SensorManager_HealthName(h));
        UART2_SendString(buf);
    }
}

/* ── Main ────────────────────────────────────────────────────────── */
int main(void)
{
    /* 1. Clock first */
    SystemClock_Config_80MHz();
    SysTick_Init();

    reset_cause_t reset_cause = Watchdog_GetResetCause();
    (void)reset_cause;   /* reported below once UART is up */

    /* 2. Basic I/O — E-stop sense and load driver come up before anything
     * that could energize hardware, so their fail-safe defaults hold. */
    LED_Init();
    UART2_Init();
    Load_Init();          /* PC8 low + PC9 input before all else */
    Estop_Init();         /* PA0 input, no pull */
    LED_On();

    {
        char boot[64];
        size_t bn = Protocol_EncodeBoot(boot, sizeof(boot), OSBAMS_FW_VERSION_STR);
        if (bn) UART2_SendBytes((const uint8_t *)boot, (uint16_t)bn);
    }
    delay_ms(50);

    /* 3. Test controller */
    TestController_Init();
    TestController_ProcessEvent(TEST_EVT_INIT_DONE);   /* BOOT -> SELF_TEST */

    /* 4. Sensor Manager */
    osbams_status_t sensor_st = SensorManager_Init(&g_sensors);

    AdcSafety_Init();
    AcquisitionTimer_Init(OSBAMS_SAMPLE_PERIOD_MS);
    AcquisitionTimer_Start();
    Watchdog_Init(OSBAMS_SAMPLE_PERIOD_MS * 4U);
    ReportSensorHealth();

    /* 5/6. Measurement + Safety */
    Measurement_Init(&g_measure, &g_sensors);
    Safety_Init(&g_safety);

    /* 7. Boot self-test: sensor init result + the shared checks. Failure
     * latches FAULT but no longer hangs the MCU — telemetry and the ACK
     * path stay alive so the operator can see why and recover. */
    if (sensor_st != OSBAMS_STATUS_OK) {
        Fault("SENSOR_INIT");
    } else if (!RunSelfChecks()) {
        Fault("SELFTEST_BOOT");
    } else {
        TestController_ProcessEvent(TEST_EVT_PRECHECK_PASS);
        UART2_SendString("OSBAMS,STATE,IDLE\r\n");
    }
    LED_Off();

    /* 8. Main loop */
    uint32_t last_recovery_ms = 0;
    g_test_start_ms = Tick_GetMs();     /* boot-time value; reset again on
                                          * entering DISCHARGING below */
    test_state_t prev_state = TestController_GetState();

    while (1)
    {
        test_state_t state = TestController_GetState();

        /* FIX: reset the test-duration clock on the transition INTO
         * DISCHARGING, not just once at boot. See g_test_start_ms's
         * declaration comment.
         * HONEST CAVEAT: main.c does not yet drive TEST_EVT_START anywhere
         * (that's the separate, larger "main.c doesn't implement the
         * actual discharge-test control loop" gap — Load_Enable() is
         * never called here either). So this transition is currently
         * unreachable in practice; it's here so the timer logic is
         * correct and ready the moment that control loop gets built,
         * rather than being a second bug discovered later. */
        if (state == TEST_DISCHARGING && prev_state != TEST_DISCHARGING) {
            g_test_start_ms = Tick_GetMs();
        }
        prev_state = state;

        /* Heartbeat: solid in FAULT/E_STOP, blink otherwise */
        if (state == TEST_FAULT || state == TEST_ESTOP) LED_On();
        else if ((Tick_GetMs() % 1000) < 50) LED_On(); else LED_Off();

        /* ── E-stop: every iteration, before anything else ────────── */
        Estop_Poll();
        if (Estop_IsTripped() && state != TEST_ESTOP) {
            EnterEstop();
            state = TEST_ESTOP;
        }

        /* ── Contactor supervision: commanded OFF but AUX ON = welded.
         * Only meaningful when we believe the load is off; the ON-path
         * confirmation happens inside Load_Enable() itself. ────────── */
        if (!Load_IsEnabled() && state != TEST_FAULT && state != TEST_ESTOP) {
            if (Load_ConfirmOffByCurrent(g_measure.latest.current_ma)
                    == OSBAMS_STATUS_LOAD_STUCK) {
                Fault("CONTACTOR_WELDED");
                state = TEST_FAULT;
            }
        }

        /* ── Operator commands (ACK) ──────────────────────────────── */
        PollOperatorCommand();
        state = TestController_GetState();   /* ACK may have changed it */

        /* ── Periodic sensor recovery (unchanged) ─────────────────── */
        if (Tick_ElapsedMs(last_recovery_ms) >= 10000) {
            last_recovery_ms = Tick_GetMs();
            SensorManager_AttemptRecovery(&g_sensors);
        }

        /* ── Deterministic acquisition ────────────────────────────── */
        if (!AcquisitionTimer_SampleDue()) {
            Watchdog_Refresh();
            continue;
        }
        Watchdog_ReportHeartbeat(WD_ACQUISITION_HEARTBEAT);

        uint64_t ts_us = (uint64_t)Tick_GetMs() * 1000ULL;
        osbams_status_t acq = Measurement_Acquire(&g_measure, ts_us);
        (void)acq;

        const measurement_sample_t *s = &g_measure.latest;

        /* ── Safety evaluation: runs in EVERY state, including FAULT and
         * E_STOP — a latched system still watches its sensors. New faults
         * while already latched are re-latched in the safety context (the
         * controller stays where it is; E_STOP is not demoted). ─────── */
        uint32_t elapsed_s = Tick_ElapsedMs(g_test_start_ms) / 1000;
        fault_code_t fault = Safety_Evaluate(&g_safety, &g_limits, s, elapsed_s);
        Watchdog_ReportHeartbeat(WD_SAFETY_HEARTBEAT);
        Watchdog_ReportHeartbeat(WD_CONTROLLER_HEARTBEAT);

        if (fault != FAULT_NONE && g_safety.fault_latched
            && state != TEST_FAULT && state != TEST_ESTOP) {
            char fb[32];
            snprintf(fb, sizeof(fb), "FAULT_%d", (int)fault);
            Fault(fb);
            state = TEST_FAULT;
        }

        /* ── Telemetry frame (CRC-protected, carries the state name) ── */
        char frame[PROTOCOL_FRAME_MAX];
        size_t n = Protocol_EncodeData(frame, sizeof(frame), s,
                                       TestController_GetState());
        if (n) UART2_SendBytes((const uint8_t *)frame, (uint16_t)n);
    }
}

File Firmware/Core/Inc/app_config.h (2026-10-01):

/*
 * app_config.h — RECONSTRUCTED. Two kinds of values here:
 *
 * (a) FROZEN per DESIGN_DECISIONS.md / the build-order review:
 *     OSBAMS_SHUNT_MICRO_OHM, OSBAMS_INA228_IMAX_MA,
 *     OSBAMS_DEFAULT_MAX_CURRENT_MA.
 *
 * (b) Evidence-based defaults: pulled verbatim from the `safety_limits_t
 *     lim = {...}` literal in test_safety_modules.c, which is the only
 *     real source-of-truth for these numbers seen anywhere in the
 *     uploaded files. Diff against the real app_config.h if you have one
 *     — these are NOT independently frozen the way the current
 *     thresholds are; DESIGN_DECISIONS.md explicitly says voltage/temp
 *     limits are chemistry- and sensor-placement-dependent and were
 *     deliberately left open.
 *
 * KNOWN GAP, not fixed here: the frozen fault architecture calls for
 * THREE current tiers (17.0 A warn / 18.5 A trip-with-debounce / 20.0 A
 * immediate-trip) with a "2 consecutive FRESH readings" debounce using
 * the freshness flag INA228_ReadCurrent_mA() now returns. The real
 * safety.c only implements a single `max_current_ma` threshold with no
 * debounce and doesn't consume the freshness flag at all (sensor_manager.c
 * passes NULL for it — see that file's comment). Implementing the
 * three-tier debounced logic is real work still open in safety.c, not
 * something a header change can paper over. Flagging it here so it isn't
 * lost.
 */
#ifndef APP_CONFIG_H
#define APP_CONFIG_H

/* ── INA228 / shunt — FROZEN ─────────────────────────────────────────
 * RSA-20-50 shunt: 2.5 mOhm, 20 A / 50 mV physical rating.
 * Rev.2: IMAX = 20 A digital full scale (CURRENT_LSB ~ 38.147 uA, SHUNT_CAL = 1250,
 * ADCRANGE = 0). 20 A is above the 18.5 A firmware hard trip, so the 20-bit CURRENT
 * register does not saturate at the trip point. ADCRANGE = 1 (+/-40.96 mV = 16.4 A)
 * must NOT be used: it saturates below the 18.5 A trip. (Rev.1 used 30 A / SHUNT_CAL 1875.)
 * Manufacturer data: USER_RELAYED_MANUFACTURER (docs: Hardware/Rev2_Controller/MANUFACTURER_DATA_RECONCILIATION.md). */
#define OSBAMS_SHUNT_MICRO_OHM       2500U
#define OSBAMS_INA228_IMAX_MA        20000U

/* ── Current protection — FROZEN (hard trip only; see KNOWN GAP above
 * for the still-unimplemented 17.0/18.5 warn+debounce tiers) ────────── */
#define OSBAMS_DEFAULT_MAX_CURRENT_MA  18500

/* ── Voltage / temperature / duration — evidence-based defaults from
 * test_safety_modules.c's lim struct, NOT independently frozen ─────── */
#define OSBAMS_DEFAULT_MAX_TEMP_C10    600     /* 60.0 C */
#define OSBAMS_DEFAULT_MIN_VOLTAGE_MV  30000   /* 30.0 V */
#define OSBAMS_DEFAULT_MAX_VOLTAGE_MV  44000   /* 44.0 V, margin above 42V pack max */
#define OSBAMS_MAX_TEST_DURATION_S     36000U  /* 10 hours */

/* ── Acquisition period — matches acquisition_timer.c's own worked
 * example (500 ms -> ARR=5000) ──────────────────────────────────────── */
#define OSBAMS_SAMPLE_PERIOD_MS        500U

/*
 * NOTE ON OSBAMS_TARGET_STM32: deliberately NOT defined here. Every
 * driver (i2c_bus.c is the one exception — see its own file note) gates
 * real register access behind `#ifdef OSBAMS_TARGET_STM32`, and that
 * macro is expected to come from the BUILD, not from this header — pass
 * -DOSBAMS_TARGET_STM32 on the arm-none-eabi-gcc command line for the
 * real target build; omit it entirely for host tests, matching how
 * test_measurement.c / test_safety_modules.c already build and run with
 * plain gcc.
 */

#endif /* APP_CONFIG_H */

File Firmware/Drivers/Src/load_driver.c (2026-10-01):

/*
 * load_driver.c — Electronic Load Control with Fail-Safe Disconnect
 *
 * ── Why the previous version was unsafe ──────────────────────────────
 * The scaffold set a boolean and returned OSBAMS_STATUS_OK:
 *
 *     osbams_status_t Load_Disable(void) { enabled = false; return OK; }
 *
 * That reports success without performing any hardware action. Software
 * overtemperature detection was therefore a warning, not protection.
 *
 * ── Fail-safe design ─────────────────────────────────────────────────
 * The load-enable line is ACTIVE HIGH and defaults LOW:
 *
 *   - GPIO configured as output, driven LOW, before anything else
 *   - MCU reset, brown-out, or unprogrammed state leaves the pin LOW
 *   - LOW must correspond to LOAD OFF in the external wiring
 *   - A pull-down resistor on the enable line holds it LOW if the MCU
 *     is removed or the pin goes high-impedance
 *
 * ── PC9 — FROZEN: K1 voltage-feedback via VO610A, ACTIVE LOW ─────────
 * Earlier revisions of this file went through two incorrect states:
 *   1. Claimed PC9 was a genuine Durakool aux contact (it isn't — the
 *      DG57CM-5021-76-1012-R has no aux contact).
 *   2. Correctly disabled feedback (LOAD_FEEDBACK_PRESENT 0) as a result,
 *      but that threw out real signal along with the wrong assumption:
 *      PC9 IS wired to something real — switched HV (present only when
 *      K1 is actually closed and conducting) through a resistor chain
 *      into a VO610A optocoupler, output to PC9.
 *
 * Frozen final assignment: PC9 = K1 voltage-feedback, ACTIVE LOW.
 * The VO610A's phototransistor output is open-collector and pulls the
 * line LOW when its LED conducts (i.e. when switched HV is present,
 * i.e. when K1 is closed) — external pull-up brings it HIGH when the
 * LED is dark (K1 open). So:
 *
 *     PC9 LOW  = K1 closed, HV present downstream  (load ON, confirmed)
 *     PC9 HIGH = K1 open, no HV downstream           (load OFF, confirmed)
 *
 * This is the OPPOSITE polarity of the old (wrong) active-high aux-
 * contact assumption this file previously carried, and it is DEFINITIVE
 * position feedback (proves HV actually flows through the closed
 * contacts) — arguably stronger evidence than a mechanical aux contact
 * would have been, which only proves the armature moved.
 *
 * LOAD_FEEDBACK_PRESENT is back to 1. feedback_says_load_on() inverts
 * the raw read (see its own comment) so every caller above it keeps the
 * same "true = load confirmed on" contract regardless of the wire-level
 * polarity — nothing outside this file needs to know PC9 is active-low.
 *
 * PC9 / K1_AUX macro name kept as LOAD_FEEDBACK_PIN for continuity with
 * existing call sites; it is documented here as the VO610A signal, not
 * a mechanical aux contact.
 */

#include "load_driver.h"
#include "app_config.h"
#include "tick.h"

#ifdef OSBAMS_TARGET_STM32
#include "stm32l476xx.h"
#endif

/* ── Pin configuration ────────────────────────────────────────────── */
#define LOAD_ENABLE_PORT      GPIOC
#define LOAD_ENABLE_PIN       8U        /* PC8: load enable, ACTIVE HIGH */
#define LOAD_FEEDBACK_PORT    GPIOC
#define LOAD_FEEDBACK_PIN     9U        /* PC9: K1 voltage-feedback via
                                          * VO610A optocoupler, ACTIVE LOW.
                                          * See file header — frozen. */

/* FROZEN: PC9 carries real, definitive K1 position feedback (VO610A
 * sensing switched HV downstream of the contactor), active-low. */
#define LOAD_FEEDBACK_PRESENT 1

/* Current below this is treated as "load is off" when using method C. */
#define LOAD_OFF_CURRENT_MA   100

/* Real millisecond timeouts. */
#define LOAD_CLOSE_TIMEOUT_MS 250U   /* frozen: contactor close confirmation */
#define LOAD_OPEN_TIMEOUT_MS  250U   /* defensive default, not bench-confirmed */

/* ── State ───────────────────────────────────────────────────────── */
static bool     s_commanded_on   = false;
static bool     s_initialized    = false;
static uint32_t s_disable_count  = 0;
static uint32_t s_confirm_fails  = 0;

/* ── Low-level pin control ───────────────────────────────────────── */

static void enable_pin_low(void)
{
#ifdef OSBAMS_TARGET_STM32
    LOAD_ENABLE_PORT->BSRR = (1U << (LOAD_ENABLE_PIN + 16));  /* reset */
#endif
}

static void enable_pin_high(void)
{
#ifdef OSBAMS_TARGET_STM32
    LOAD_ENABLE_PORT->BSRR = (1U << LOAD_ENABLE_PIN);         /* set */
#endif
}

bool Load_DecodeFeedbackActiveLow(bool raw_bit_is_set)
{
    /* Active low: LOW (bit clear) = confirmed on. */
    return !raw_bit_is_set;
}

static bool feedback_says_load_on(void)
{
#if LOAD_FEEDBACK_PRESENT && defined(OSBAMS_TARGET_STM32)
    bool raw_high = (LOAD_FEEDBACK_PORT->IDR & (1U << LOAD_FEEDBACK_PIN)) != 0;
    return Load_DecodeFeedbackActiveLow(raw_high);
#else
    /* Host build, or feedback not wired: report false. On host this keeps
     * Load_Enable()/Load_Disable() from ever looping on real time (there's
     * no SysTick incrementing tick.h's counter outside the target), so
     * tests exercise the logic paths once and return deterministically —
     * see the single-check branches below. The polarity DECODE logic
     * itself (Load_DecodeFeedbackActiveLow) is still exercised directly
     * by the host test suite, independent of this hardware gate. */
    return false;
#endif
}

/* ── Init: fail-safe state first ─────────────────────────────────── */

osbams_status_t Load_Init(void)
{
#ifdef OSBAMS_TARGET_STM32
    RCC->AHB2ENR |= RCC_AHB2ENR_GPIOCEN;

    /* Drive LOW *before* switching the pin to output so the line never
     * glitches high during configuration. */
    enable_pin_low();

    /* Enable pin: push-pull output, low speed */
    LOAD_ENABLE_PORT->MODER &= ~(3U << (LOAD_ENABLE_PIN * 2));
    LOAD_ENABLE_PORT->MODER |=  (1U << (LOAD_ENABLE_PIN * 2));
    LOAD_ENABLE_PORT->OTYPER &= ~(1U << LOAD_ENABLE_PIN);
    /* Internal pull-down as a second line of defence */
    LOAD_ENABLE_PORT->PUPDR &= ~(3U << (LOAD_ENABLE_PIN * 2));
    LOAD_ENABLE_PORT->PUPDR |=  (2U << (LOAD_ENABLE_PIN * 2));

    enable_pin_low();

#if LOAD_FEEDBACK_PRESENT
    /* Feedback pin: input with internal pull-up as a fail-safe backup to
     * the VO610A circuit's own external pull-up. PC9 is ACTIVE LOW
     * (LOW = K1 closed/HV present), so the safe default if the pull-up
     * path fails is to read HIGH -- "K1 open" / "not confirmed closed"
     * -- not to default toward a false "closed" reading. A pull-DOWN
     * here would fight the active-low idle-high convention and risk a
     * floating pin misreading as "closed" if the external pull-up ever
     * fails open. */
    LOAD_FEEDBACK_PORT->MODER &= ~(3U << (LOAD_FEEDBACK_PIN * 2));
    LOAD_FEEDBACK_PORT->PUPDR &= ~(3U << (LOAD_FEEDBACK_PIN * 2));
    LOAD_FEEDBACK_PORT->PUPDR |=  (1U << (LOAD_FEEDBACK_PIN * 2));
#endif
#endif

    s_commanded_on  = false;
    s_initialized   = true;
    s_disable_count = 0;
    s_confirm_fails = 0;
    return OSBAMS_STATUS_OK;
}
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

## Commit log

2026-10-01 OSBAMS Rev.2 initial public release
    [01_Power_Input.kicad_sch, 01_Probe.kicad_sch, 02_Buck_3V3.kicad_sch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]
2026-10-02 Add calibration/validation layer, protocol v2 host reference, Battery Passport, dataset export, Settings screens, and experimental ai/ area
    Under development. Host-tested only: no bench data yet, all thresholds provisional until reference-instrument
    validation, Rev.2 remains unbench-validated until first article. AI health estimation is experimental/research-stage;
    capacity retention vs rated is not a validated cell-level SOH. Firmware still speaks protocol v1.
    - calibration fit/store, Ah/Wh integration with real timestamps, measurement-quality report, repeatability, DCIR conditions
    - protocol v2 reference parser + golden vectors; three-way capacity validation (CAPACITY_VALIDATION_WARNING,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
    [calibration_points.csv, fault_injection.csv, reference_validation.csv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]
